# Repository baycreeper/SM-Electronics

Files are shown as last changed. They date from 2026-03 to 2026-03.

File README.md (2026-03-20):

# Foothill High School Supermileage Club  
## Electronics System – Shell Eco-Marathon Vehicle (Prototype)

## ⚡ Overview
This repository contains all electronics-related design, development, and testing for the Foothill High School Supermileage Club’s Shell Eco-Marathon vehicle.

It focuses on the vehicle’s electrical and control systems, including the ECU, wiring, sensors, and data acquisition.

---

## 🎯 Objectives
- Develop a reliable and efficient electronic control system  
- Enable precise fuel and engine management  
- Collect and analyze performance data  
- Ensure safe and robust electrical design

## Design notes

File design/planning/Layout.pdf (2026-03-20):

CSharp

- Vacuum hose
- Power & Distribution
- 12V Accessory battery (LiFePO4 1-2 Ah)

Battery +12V
├─10A fuse─> MainRelay(30) ──> ECU + injector + coil + sensors └─PumpRelay(30) ──> Fuel Pump +
Speeduino Fuel Pump out ──> grounds PumpRelay(85)
Relay(86) ──> +12V switched
Injector - ──> Speeduino INJ1
Ignition Coil - ──> Speeduino IGN1 / IGBT Driver

Total schematic:

+----------------+
| 12V LiFePO4 | |
| | Battery | |
+--------+-------+
| 12 AWG Red (Fused 30A)
v
+----------------+
| Master Cutoff |
| | Switch | |
+--------+-------+
| 12 AWG Red
v
+------------------+
| Fuse / Relay Box |
| | | 6-way sealed | |
+--------+---------+

+------------------------+-------------------------+-------------------+
+--------+--------+ | +--------+--------+ | +--------+--------+
| Main Relay | | | | Fuel Pump Relay | | | Starter Relay | |
| (30A SPDT) | | | | (30A SPDT) | | | | (30A SPDT) | |
+--------+--------+ | +--------+--------+ | +--------+--------+

+-------------+-------------+ | 16 AWG Red | 12 AWG Yellow
| Speeduino ECU + Sensors | |------------------------------> Starter Motor +
| | | | (through ESC if
used)
| | +-------------------+ | |
| | | Fuel Injector(s) |<--+ 18 AWG Yellow, low-side switching
| | +-------------------+
| | +-------------------+
| | | Ignition Coil | |<-- 16–18 AWG Blue, logic coil or IGBT driver
| | +-------------------+
| | +-------------------+
| | | Crankshaft Sensor |<-- 22 AWG Green/White Shielded
| | +-------------------+
| | +-------------------+
| | | TPS | |<-- 22 AWG Orange
| | +-------------------+
| | +-------------------+
| | | MAP | |<-- 22 AWG Gray
| | +-------------------+
| | +-------------------+
| | | IAT | |<-- 22 AWG Violet
| | +-------------------+
| | +-------------------+
| | | CLT | |<-- 22 AWG Brown
| | +-------------------+
| | +-------------------+
| | | O₂ Wideband | |<-- 16 AWG White (Heater + 0–5V signal 22 AWG)
| | +-------------------+

+-------------------+
| Accessory Relay | |------------------> IMU, GPS, HUD, Camera, Horn
| 5–10A Fused | |
+-------------------+
| 18–20 AWG Blue/Green
v

+--------------+
| HC-05 + MCU |--> Tablet RealDash +--------------+

+-------------------+
| E-Stop Switch |
| (cuts master relay)|
+-------------------+
+--> Cuts power to all fused relays / ECU inputs

# Electrical Parts List – Nested by Subsystem

1️⃣Power & Safety

- Battery
- 12V LiFePO4, 1–2Ah
- Connect to master cutoff: 12 AWG Red
- Ground to chassis: 12 AWG Black
- Master Cutoff Switch
- Inline with battery +12V
- Wire: 12 AWG Red
- E-Stop Switch (NC)
- Inline with all critical relay coils
- Wire: 14–16 AWG Red
- Fuse / Relay Block (6-way)

- Holds fuses & relays
- Fuses:

■ ECU / Injectors / Ignition: 10A

■ Fuel Pump: 10A

■ Starter: 30A

■ Accessories: 5–10A

- Wire: same as downstream devices

2️⃣ECU / Speeduino

- Speeduino 0.3.7
- Power +12V: 20 AWG Red (via Main Relay + ECU power fuse)
- Ground: 12 AWG Black
- Arduino Mega 2560
- Mounted to Speeduino PCB
- Inputs / Outputs
- TPS: 22 AWG Orange
- MAP: 22 AWG Gray
- IAT: 22 AWG Violet
- CLT: 22 AWG Brown
- Crank Hall Sensor: 22 AWG Green/White (shielded)
- O₂: 22 AWG White (+16 AWG Red Heater)

- Injectors: 18 AWG Yellow
- Ignition Coil Trigger: 16–18 AWG Blue
- Fuel Pump Trigger: 22 AWG Black (feeds relay)
- Starter Trigger (if using MCU control): 22 AWG Blue/Green

3️⃣Fuel System

- Fuel Pump
- +12V via Fuel Pump Relay output 87
- Fuse: 10A near pump
- Wire: 16 AWG Red
- Ground: Battery GND / chassis, 12 AWG Black
- Fuel Pump Relay
- Coil 85 → E-Stop output
- Coil 86 → Battery +12V
- Injectors
- Low-Side Trigger: Speeduino output, 18 AWG Yellow
- Power: 20 AWG Red from ECU power fuse
- Ground: ECU common GND

4️⃣Ignition System

- Ignition Coil / CDI

- Low-side driver from Speeduino: 16–18 AWG Blue
- +12V power via Main Relay: 16–18 AWG Red
- Fuse: Included in Main Relay branch
- Optional: external small relay if coil >1A
- Crankshaft Position Sensor
- 22 AWG Shielded Green/White
- Signal → Speeduino input

5️⃣Starter System

- Starter Motor
- +12V via Starter Relay output 87
- Fuse: 30A near motor
- Wire: 12–14 AWG Yellow
- Ground: Battery / chassis, 12 AWG Black
- Starter Relay
- Coil 85 → E-Stop output
- Coil 86 → Ignition-on / MCU
- Starter ESC (if brushless)
- Control wires connected to MCU / relay

6️⃣Accessories / Telemetry

- Accessory Relay
- Coil 85 → +12V via Ignition-on (optional E-Stop)
- Coil 86 → Ignition-on / MCU trigger
- Output 87 → Accessories
- Devices
- IMU: 18–20 AWG Red/Black
- HUD Display / Mini OLED: 18–20 AWG Red/Black
- GPS Module: 18–20 AWG Red/Black
- Camera / Horn: 18–20 AWG Red/Black
- Optional HC-05 Bluetooth Module
- Connect to Speeduino serial RX/TX
- 5V logic from Arduino / Speeduino
- Wire: 22 AWG

7️⃣Wiring & Harness Supplies

- Wire
- 12 AWG Red/Black (battery, starter)
- 14–16 AWG Red (relay coil feeds / E-Stop)
- 16 AWG Red (fuel pump, ignition power)
- 16–18 AWG Blue (ignition coil low-side)
- 18 AWG Yellow (injectors)

- 18–20 AWG Red/Blue/Green (accessories)
- 22 AWG Various / Shielded (sensors, triggers)
- Connectors
- Deutsch DT / TE Superseal for critical sensors
- Crimp terminals for relays/fuses
- Male/female pins for ECU / sensors
- Harness Protection
- Braided sleeving
- Heat shrink tubing (3/16–1/4”)
- Cable ties, grommets, rubber pass-throughs \\

PAAAAARTS:

- 12V LiPO4 Battery (w/ BMS and overcurrent protection) **some battery idk ■
- Main fuse box & relay box
■ https://www.amazon.com/Malictele-Pre-Wired-Relays-Sealed-Waterproof/dp/B0CYGQKGHW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 x&pd_rd_i=B0CYGQKGHW&pd_rd_r=0ccad619-9752-4f9c-a397-e825cc a8e9e7&pd_rd_w=BWabo&pd_rd_wg=Dkl5C&pf_rd_p=9ce0d71e-7aca-4 397-8822-32313a4aff8e&pf_rd_r=YBM79NVD1K1HDZCW8GMF&qid=17 59884967&sbo=RZvfv%2F%2FHxDF%2BO5021pAnSA%3D%3D&sprefi x=automotive%2Bfuse%2Bbo%2Caps%2C204&sr=1-3-6024b2a3-78e4-4 fed-8fed-e1613be3bcce-spons&sp_csd=d2lkZ2V0TmFtZT1zcF9zZWFyY 2hfdGhlbWF0aWM&th=1 (https://www.amazon.com/Malictele-Pre-Wired-Relays-Sealed-Waterproof/dp/B0CYGQKGHW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)
- Main, fuel, ignition, starter relays, +1 (to ECU) **GET FOUR ■ https://www.amazon.com/Bosch-0986332030-Relay/dp/B00BHIM4N0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 (https://www.amazon.com/Bosch-0986332030-Relay/dp/B00BHIM4N0?s=industrial)

_6pjIJOkdotmROLds-fhNYCFSRpgm6-MZwHdaVL2wg179iRALKoRrWO 2HftzRYREI59EydOU4_71FkI-wiJcofJA8ib_xxloiDfJ862q5McWQ7dyYA8 OTeCyC95pZgDFxWLzUAT6Cxd6cwxIiP1LeDjGHjQC4sMbdApo3A3hW MGDXL62uquE3oo7url6X_NlMNqz4Ot3UU6Mht_XKwhtkmX5wQl2eM-pn 5Ehns1ViQCJ85cdCNgMeulPYJamHvQMwclC2waPOJwXQjjOcV_L5oCn CSw.2R0y7E6n32U7Tc2AK_UGtvRN4aG31h4pdcQzQ6KqyMM&dib_tag =se&keywords=4+pin+bosch+relays+40A&qid=1759884191&s=industrial &sprefix=4+pin+bosch+relays+40a%2Cindustrial%2C145&sr=1-3 (https://www.amazon.com/Bosch-0986332030-Relay/dp/B00BHIM4N0?s=industrial)
- E-Stop (connect to signal line for main relay) ■ https://www.amazon.com/API-ELE-Warranty-Emergency-Latching-Stianless/dp/B08QD31NNC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 2IjoiMSJ9.o0JLMga4CanfnAaJZnGvPmo8cMM38jChPtEgBaRhodWKAtf YG2sZ6NugYS5MTmdwmcF9rJUZ1Ok1gAzY-Gpa-ApzU-QPTctDBXxXnb 8nJzA42jE24lzyD5k_zYC1TzuRRT1DRGbI5iLHiVpuzJpXf6g0-VxnOMiU_ WRCoFMp9tI14V_8IU04TLUWQf4T89V1UVirAMYJH7nSDJnaIy-UNLZA gkiZs-lH3T5TADT--js.zilyJC3X59NI8hIOy3OikqIApiORAC9azPxZBqZS7T 8&dib_tag=se&keywords=emergency%2Bstop%2Bpush%2Bbutton%2Ba utomotive&qid=1759883196&sprefix=emergency%2Bstop%2Bpush%2Bb utton%2Bautomotiv%2Caps%2C170&sr=8-2-spons&sp_csd=d2lkZ2V0T mFtZT1zcF9hdGY&th=1 (https://www.amazon.com/API-ELE-Warranty-Emergency-Latching-Stianless/dp/B08QD31NNC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)
- 12V-5V convertor (for tablet) [3A fuse]
- https://www.amazon.com/Converter-Module-Output-Adapter-Regulator/dp/B08RBWX2GL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 VH9xdmECVZ0jwP1hnqZ0YLrX33tLWmshWiAj430sqsfUZKdYqSj6XqW9KttgEp GZwl6OSc5wZxtVDTW9besYZTQNYZdCzhF9ErowIhZ3AWHXjZEtzb_YlqXz7Ry WOU9eP0Gu0dDmVYnZAv1Nxin7eTJ4svPEkIBhOPA6sCHp27s1cAyt1O5yGkg bet5HCXCUdVHO5QvAGllQAu-sIR6gv9uUkIhV5PR3a74.WjvNA9GEC6PXa5oV NugpibUZOIEtFGED7wYVzY9-9YY&dib_tag=se&keywords=5v%2B3a%2Busb% 2Bbuck%2Bconverter&qid=1759883591&sprefix=5v%2B3a%2Busbc%2Bbuck% 2Bconverter%2Caps%2C545&sr=8-2-spons&sp_csd=d2lkZ2V0TmFtZT1zcF9hd GY&th=1 (https://www.amazon.com/Converter-Module-Output-Adapter-Regulator/dp/B08RBWX2GL?sp_csd=d2lkZ2V0TmFtZT1zcF9hdGY)
- Fuse assortment (5A-30A) ■ https://www.amazon.com/Liamner-Assortment-Automotive-Motorcycle-Accessories/dp/B0DSJQTBVY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 peOn2UvqdKm4-KeyhsO93sE1x2NUi4XvdQBKWENYU8HDVRTM-iM7D ZoVAi4YQ7BH2KlIXGBoLJdYRIQCJuNfv0LA2f6L-7b5UPXH8tgi-0Kw6FC xEqmEKSL5qeD7cG4XH-ok7DU_j4lqB_mGgoPiuIualk6MRItoIkkT01HMiI Hq171FdEhqpAI7pq0c.TqBq9xa4UnOCYl8BaOFEHiLZZw6a00PaM4aPH 3KboTQ&dib_tag=se&keywords=AOC+mini+fuse+assortment&qid=17598 87110&sprefix=aoc+mini+fuse+assortment%2Caps%2C167&sr=8-1 (https://www.amazon.com/Liamner-Assortment-Automotive-Motorcycle-Accessories/dp/B0DSJQTBVY)
- Fuse for starter motor?
■
- MAXI fuse and holder (60A for battery)

■ https://www.amazon.com/Fastronix-High-Current-Covered-Holder/dp/B071CWH241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 OyDbObYc7h0ohrCkImUPGt8pdZfLrDFRDCbYXeHqOmv13DuO7B0tmn OaXvVvYOAWoR03BNsoLqlYHP-z82-hqLmBUi4kxpRsbyHbDuOqf0W0F 5ahnzg1IufPe0_q6yWC92_R5snAh6xwt-0-jTUQ1G9GMbdngbx_E_WDg K8L-O-7AukdFz7v8afGK4i7gaWwAkEc-KzsRWf4FpOts1__GrNov5VMJy 4FBCi9ZuXv3m2TBPcqU-yCG2Tfqz_Eq5xy5Bccz53BqsCMLU0dZV2P-o HS7qQ_w4CZSv_wCPfvw.s3P_oNkJUBQzijacT2YlqlStRH0rLb-tMhsJGJ 6tWZM&dib_tag=se&keywords=4+gauge+maxi+fuse+holder&qid=175988 5819&s=industrial&sprefix=4+guage+maxi+fuse+hold%2Cindustrial%2C1 49&sr=1-1-spons&sp_csd=d2lkZ2V0TmFtZT1zcF9hdGY&psc=1 (https://www.amazon.com/Fastronix-High-Current-Covered-Holder/dp/B071CWH241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)
- Ground bus bar (gnd for all the big boy current drinkers ex: battery, main relay, starter, fuel pump, ignition coil, etc)
■ https://www.amazon.com/Blue-Sea-Systems-Common-10-Gang/dp/B000K2MA9C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 Gd9FWTFyROoUiB2JJM3rmfct5Z9jAt8608B1yf4tKwMNtOx1bf9goUAQS VTXeVB-E71EPEZy8t9An5igc07s8GqcQmO0IYiqjo50.sg8zklWyqZG9AC XOWXQYlM4hfMfPpOX3ROyA3xjvVBg&dib_tag=se&hvadid=241912403 694&hvdev=c&hvexpln=0&hvlocphy=9032030&hvnetw=g&hvocijid=9473 815932346308800--&hvqmt=e&hvrand=9473815932346308800&hvtargid =kwd-6778157821&hydadcr=24662_10400876&keywords=blue+sea+230 1&mcid=44dfa469103b3366b2c2f3116110850d&qid=1759886674&sr=8-1 (https://www.amazon.com/Blue-Sea-Systems-Common-10-Gang/dp/B000K2MA9C?hvadid=241912403694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)
- Terminal Block
- (to split ECU power to all sensors and HC-05 and ignition relays)
■ https://www.amazon.com/Joinfworld-Terminal-Position-Pre-Insulated-Jumper/dp/B0BN55WVDB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 9032030&hvnetw=g&hvocijid=12081548633357188257--&hvqmt=e&hvra nd=12081548633357188257&hvtargid=kwd-1194057008&hydadcr=2463 0_10399594&keywords=insulated%2Bterminal%2Bblock&mcid=66f90a89 f488390f8d4f5ba1b62b9963&pd_rd_i=B0BN55WVDB&pd_rd_r=6662406 2-985e-4507-91fc-76a4ed1845a3&pd_rd_w=9mHBV&pd_rd_wg=xR0ng& pf_rd_p=9ce0d71e-7aca-4397-8822-32313a4aff8e&pf_rd_r=CMT6YTPY SGJ2YR5PZ857&qid=1759886961&sbo=9ZOMT9Jm0JH%2Ft%2BWi68i DSA%3D%3D&sr=1-2-6024b2a3-78e4-4fed-8fed-e1613be3bcce-spons& sp_csd=d2lkZ2V0TmFtZT1zcF9zZWFyY2hfdGhlbWF0aWM&th=1 (https://www.amazon.com/Joinfworld-Terminal-Position-Pre-Insulated-Jumper/dp/B0BN55WVDB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)
- Common gnd bus (for small sensors)
■ https://www.amazon.com/Bonsicoky-Terminal-Positions-Electrical-Grounding/dp/B097R5J66D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 (https://www.amazon.com/Bonsicoky-Terminal-Positions-Electrical-Grounding/dp/B097R5J66D)

J9.o3aAIQFhu_-oQy_cjH_gGr-I2ZsUD2van3ZxTJFIcuCGtwjsV_0a02c06 xmGgAsweLC_Z7s8BrkThGN9AE2FHt6aSQ5IIX0xm6AywIxyYmkjc037W nkoc7aHFneKdHEK9K7xrVlhkaOnULBed569N-pp-0vxnDiirp3qnsHDPBm eOkuzUH1762MrlZQMN0zGQIZrdOFa-srUtJsQnGndByVy5Y_iN0x7BqRJ wkpjwacSbjMiRnEtuu5OaBVW9xk3zcHL_uoTfN8-jhZxIzkypbC-lzw2f7pjC WYmur6nO-Q.0BQxbNhj80H8sG3uCdPtALvmOI-11KQYgsoqWwOeHoE &dib_tag=se&keywords=ground+bus+bar&qid=1759886729&sprefix=grou nd+bus+ba%2Caps%2C175&sr=8-7 (https://www.amazon.com/Bonsicoky-Terminal-Positions-Electrical-Grounding/dp/B097R5J66D)
- Weatherproof connectors (2,3,4 pin) **NOT for starter, battery, ignition coil, fuel pump
- https://www.amazon.com/Amliber-Ratcheting-Connectors-Automotive-Electrical/dp/B0BZBZHVQ6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 zAnfMxUcfN6BGmdwt5Fa-O5jgd5LWTOkXMDiTed4VdjJUsZi6d2bUyfEGK8lH8jY 5wxCZjeV2T30tmA5C5OToGBfZSgM.FDl0ZpkyE-u2IbWTmRl7XDYJEIyOgQPV hL9bX9JeItI&dib_tag=se&hvadid=703719639063&hvdev=c&hvexpln=0&hvlocph y=9032030&hvnetw=g&hvocijid=16756300949084176163--&hvqmt=e&hvrand=1 6756300949084176163&hvtargid=kwd-377730786898&hydadcr=11111_1366393 0&keywords=deutsch+style+connectors&mcid=107fbdab59613c62889eed84540 b970b&qid=1759887500&sr=8-1-spons&sp_csd=d2lkZ2V0TmFtZT1zcF9hdGY& psc=1 (https://www.amazon.com/Amliber-Ratcheting-Connectors-Automotive-Electrical/dp/B0BZBZHVQ6?hvadid=703719639063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)
- Ring Terminals
- 8 AWG for battery
- Butt splice connectors (heat shrink typed)
- In case a wire is too short or we have some cuts (use solder+silicone for high current loads the big 4)
■ https://www.amazon.com/TICONN-120PCS-Heat-Shrink-Connectors/dp/B0CT3YCD5B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 J9.h2nMOlQHGbm4s-HtC2fI2Mn6QzWhqcSuMnBS7vmVtfj7reFlekePrjO nEPE0T99HzLrJJNGTbhKJvOm_-Ez1LZ69GXCr6ofYBboRl_fx7Wp9PXs TXcyhKwLx7i14xK2z1-PewJSGXrPHWb5LsKe_kELwcM-1Z9T7aCsYow mQQaaOwdLT8mZtj0QZKZi5zMUg6ar-F0_TrM_N-qUhVorWlDfxydkMC7 BDQEWOQjdQR1s.eirYoBGIm_v91z-uYityp1qdKbkgUVmnK7849dazY90 &dib_tag=se&keywords=butt%2Bsplice%2Bconnectors&qid=1759888070 &sprefix=butt%2Bsplice%2Bcpnnector%2Caps%2C181&sr=8-2-spons&s p_csd=d2lkZ2V0TmFtZT1zcF9hdGY&th=1 (https://www.amazon.com/TICONN-120PCS-Heat-Shrink-Connectors/dp/B0CT3YCD5B?sp_csd=d2lkZ2V0TmFtZT1zcF9hdGY)
- Wires
- 16 AWG
- 14 AWG
- 12 AWG
- 8 AWG
- Wire loom
- https://www.amazon.com/Keco-100ft-Expandable-Braided-Sleeving/dp/B07K1XJNJN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 (https://www.amazon.com/Keco-100ft-Expandable-Braided-Sleeving/dp/B07K1XJNJN?sp_csd=d2lkZ2V0TmFtZT1zcF9tdGY)

_GcjXVTBsnnylxO8rXuyvDd9CJXLN1dBDwPHXRQ134gVffN5JSnXL5Ig-Bp0lovI CQUDsoAUzaELJ8_rCftOajxk95Zv5_x7ri-YDqtbYowp2Khj6_by7HNDUTme49W MpIX9sorwrS_ahVBW5CEr9_1eAIaKI4gRMUkxxGbPDXJWQOjO2dwwBTr3qJ6 T_kZd8ytMnHG1c_snYg0bb9tHprbSWjys5pHL0w.XJ5h0lHsc4v_z16W0fzsh5b5T xc_lgPtqekMdtYSJlw&dib_tag=se&keywords=techflex%2Bloom%2Bautomotive& qid=1759888848&sprefix=techflex%2Bloom%2Bautomotiv%2Caps%2C149&sr= 8-12-spons&sp_csd=d2lkZ2V0TmFtZT1zcF9tdGY&th=1 (https://www.amazon.com/Keco-100ft-Expandable-Braided-Sleeving/dp/B07K1XJNJN?sp_csd=d2lkZ2V0TmFtZT1zcF9tdGY)
- Heat shrink tubing assortment
- https://www.amazon.com/108PCS-Heat-Shrink-Tubing-Kit/dp/B0FB8PD9NF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 sl77dMhn6QpNs5sBhJv7Ajw.aEplN0LRMrwJIMhf3a2GQ84KmMHfjLaUV3J_0uP xlbo&dib_tag=se&keywords=color%2Bheat%2Bshrink%2Bassortment&qid=1759 889009&sprefix=color%2Bheat%2Bshrink%2Bassortment%2Caps%2C150&sr=8 -4&th=1 (https://www.amazon.com/108PCS-Heat-Shrink-Tubing-Kit/dp/B0FB8PD9NF)
- Neutral cure silicone
■ https://www.amazon.com/BTAS-Dielectric-Automotive-Electrical-Connectors/dp/B0D6R543V2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 KeyAOrtvaDxkNA3cSqk-0hemI5krS4vBrAfuoY3ruGEsbQImrwVigZN42u QZ5lVL3gBm0r9X2TKh1yfS6WzDFam9fzm-dMgCUTU-LJMCiOkPOpwpu UNLwqGut8PCif7Y.4751hMK7ELW831SXGCY_57PYj5BGMBwtKBNxn2 heMv0&dib_tag=se&keywords=electronic%2Bsilicone&qid=1759889237& sprefix=electronic%2Bsilico%2Caps%2C166&sr=8-1-spons&sp_csd=d2lk Z2V0TmFtZT1zcF9hdGY&th=1 (https://www.amazon.com/BTAS-Dielectric-Automotive-Electrical-Connectors/dp/B0D6R543V2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)
- Fireproofing silicone
- https://www.amazon.com/Visbella-Temperature-Waterproof-Combustion-Automotive/dp/B0CPNZNQC4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 9.CC41cRqb5Un1Oyc3A4BxudsGjV14kJ2j0IIZ-QyAqBwTkDnj510G-Nu94b9VYA L-65Hhs8DwRu1LSFKiIYXEKkzZLr-LPeA88z79s-8731N2UK7gdo7UHihJF1SJwI GNAPaBwyDUgEu7fMkuEybEvHuDLRZyItReXrXu88vhOSuHyXE0eMQnZ-ch6P vgym0iLmTVsmTV0ebciaqPMKEibhP4O3fJAkj8_3YRsWwOADM.9eP6iTOxUfpK h7DYh-XDV2bOLUVV2U6EuO4jYPNgxV4&dib_tag=se&keywords=RTV%2Bhigh %2Btemp%2Bsilicone&qid=1759889310&sprefix=rtv%2Bhigh%2Btemp%2Bsilico n%2Caps%2C166&sr=8-2-spons&sp_csd=d2lkZ2V0TmFtZT1zcF9hdGY&th=1 (https://www.amazon.com/Visbella-Temperature-Waterproof-Combustion-Automotive/dp/B0CPNZNQC4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)
- Wire grommets (to pass through chassis)
- https://www.amazon.com/Double-Sided-Rubber-Grommets-Assorted-Waterproof/dp/B0B5VYYSCM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 wxxGOWEZAQZkc6mruKeFpLs6y1Kr1aOI1QXf74qrZemUR11gmWpaVdolI-G7L (https://www.amazon.com/Double-Sided-Rubber-Grommets-Assorted-Waterproof/dp/B0B5VYYSCM)

B7rGyG5PXoaCJYmlTM4Voc6WOhWRF_mXBU_amE-V-uKh_PCWxk.-TKhooN mu9NkNOOkLtq5xzSXLe3WUY8PGt4W3qK5SIw&dib_tag=se&keywords=wire% 2Bgrommets&qid=1759889343&sprefix=wire%2Bgrommet%2Caps%2C174&sr= 8-4&th=1 (https://www.amazon.com/Double-Sided-Rubber-Grommets-Assorted-Waterproof/dp/B0B5VYYSCM)
- Main battery cutoff switch
- https://www.amazon.com/Current-Battery-Disconnect-Isolator-Vehicle/dp/B0B7DR5H4H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 RwK336itQgbzR0keuOdReoqE8D_Dinu-Kz_87ZF013Y.k-_qxZe28S5i-bZT0qkU CEavM1MGbCwksUQz3gxEJ2Y&dib_tag=se&keywords=300A%2Bbattery%2Bdi sconnect%2Bswitch&qid=1759890339&sprefix=300a%2Bbattery%2Bdisconnect %2Bswitch%2Caps%2C183&sr=8-2-spons&sp_csd=d2lkZ2V0TmFtZT1zcF9hdG Y&th=1 (https://www.amazon.com/Current-Battery-Disconnect-Isolator-Vehicle/dp/B0B7DR5H4H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)

Extra:
Crimping tool
Multimeter
ECU enclosure box (are we making this?)

Final Wire List + **8 AWG wire for battery and starter

AWG | Color | Total Approx
Length

Use

12 AWG Red | 8 ft | Battery + main fuse + main relay + starter
12 AWG Black 4–5 ft | Battery negative → main ground bus / high-current
grounds
14 AWG Red | 6 ft | Main relay → fuel pump + ignition coil
14 AWG Black 3 ft | Medium-current grounds (fuel pump, ignition coil if not
chassis grounded)
16 AWG Red | 6–7 ft | ECU 12 V power input + small accessories + 5 V
step-down for tablet
16 AWG Black 12 ft | ECU / sensor grounds (split to sensors and relay coils)
16 AWG Blue | 15–20 ft | All low-current signals: TPS, MAP, IAT, CLT, Hall
sensors, HC-05, relay coils

⚙️ Core Power & Distribution

Item | Notes / Verdict
✅ 12V LiFePO₄ Battery | Perfect. 1.5–3 Ah minimum for EFI. Get one with BMS and overcurrent protection. Example: Antigravity or Shorai.
✅ Main Fuse Box | Essential. 6–8 way ATC/ATO fuse block with positive bus (Blue Sea Systems or Littelfuse).

✅ Main Relay (ECU) Good. 30–40 A automotive relay, standard SPST (Bosch-style).
| Triggers from ignition switch or E-stop return.

✅ Fuel Pump Relay Yes — same type as main relay (use socket base with pigtail).

✅ Ignition Coil Relay | Optional — if Speeduino coil output drives an igniter directly, relay not needed; but keep it for safe power control.
✅ Starter Relay | Mandatory — use a heavy-duty solenoid relay (40–100 A) depending on your starter motor draw.
✅ E-Stop | Great — choose normally closed (NC) style; wire inline with main relay trigger.
✅ 12 V → 5 V Converter (Tablet) | Good. Choose buck converter (5 A rated), 15–20 W output. Example: DROK 12V→5V 5A USB module.
✅ Fuse assortment (5A–30A) | Yes — standard ATO or mini-blade fuses.
✅ Ground Bus Bar | Yes. Use for all return grounds to battery/chassis. Get one with 6–10 screw terminals.
⚠️ Terminal Block | Keep one only. Use to split +12 V switched power for sensors, HC-05, and ignition enable. Make sure it’s rated for 15 A+ and insulated.

🔌 Connections

Item | Notes / Verdict

✅ Weatherproof Connectors (2,3,4 pin)

Excellent. Get Deutsch DT or Superseal 1.5 kits.

2-pin → IAT/CLT | Perfect.
3-pin → TPS, MAP, HC-05 | Yes.
4-pin → Injector/Coil | Yes — or 2-pin if each gets its own plug.
✅ Ring Terminals (12 AWG) | Keep — for battery, ground bar, and heavy gauge wires only.
✅ Butt Splice Connectors (heat-shrink type) | Absolutely. Get marine-grade.
✅ Inline Fuse Holder (for ECU Power) | Yes — 5A fuse inline before ECU’s +12V input.

🧵 Wiring

Gauge | Purpose | Notes
12 AWG | Battery → Main Relay, Starter Relay | Silicone-insulated, high current.
14 AWG | Relay → Fuse Box feeds, Fuel Pump | Handles 10–15 A safely.
16 AWG | Ignition Coil, Injector Power | Perfect balance of flexibility & capacity.
18 AWG | Sensors, ECU signal lines | Standard automotive control wire.
✅ Wire Loom | Yes — PET braided or split corrugated for protection.
✅ Cable Labels | Highly recommended — saves debugging headaches. Get adhesive heat-shrink ones or write-on tags.

🔧 Tools / Accessories

Item | Notes / Verdict

✅ Crimping Tool Must be a ratcheting crimper compatible with Deutsch/insulated terminals. IWISS and Wirefy make good ones.

✅ Multimeter For continuity checks, ground verification, voltage testing.

✅ ECU
Enclosure Box

Absolutely — either a 3D-printed or aluminum case. If mounting near engine, use a sealed box with grommets.

⚠️ Add These (You’ll Need Them)

Item | Purpose
Heat-shrink tubing assortment | For sealing soldered joints and strain relief.

Neutral-cure silicone (sensor
safe)

For sealing joints and connectors.

Wire grommets / strain reliefs Where the harness passes through panels or boxes.

Relay sockets with pigtails | Cleaner install for 4-5 pin Bosch relays.
Grounding ring / chassis lug | To tie the ground bus to frame solidly.
Main battery cutoff switch | For absolute power isolation when servicing.

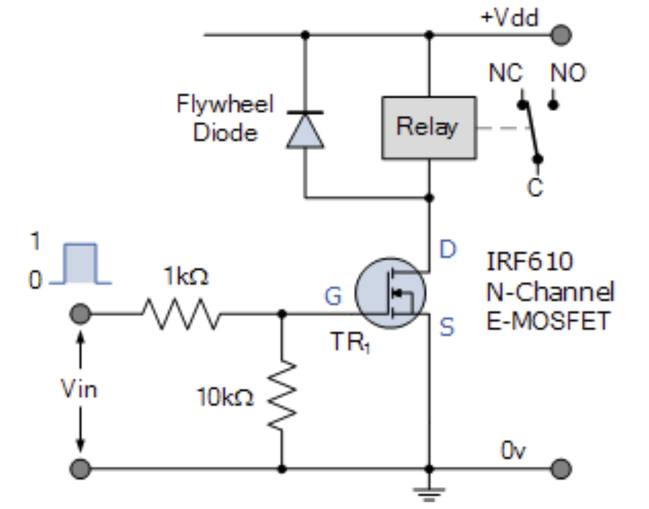
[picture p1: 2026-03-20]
design/planning/flyback diode circuit.png

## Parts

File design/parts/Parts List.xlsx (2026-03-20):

 | Description | Link | Price | Quantity | Subtotal | Total |  | DO NOT EDIT COLUMNS
 | diode-protected relay socket | https://www.amazon.com/ARTGEAR-Harness-Color-Labeled-Automotive-Motorcycle/dp/B078T8CMF6 | $7.99 | 2 | $15.98 | w/out tax | $737.65 | 737.65
 | automotive bosch relay | https://www.amazon.com/Bosch-0986332030-Relay/dp/B00BHIM4N0 | $11.29 | 3 | $33.87 | w/ tax | $813.26
 | 12 socket fuse box | https://www.amazon.com/DaierTek-Indicator-Waterproof-Terminals-Automotive/dp/B0CGT91KTR?hvadid=636053227156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 | $15.99 | 1 | $15.99 |  | AP FIND ANOTHER 6A 12V charger specifically designed for LiPO!!!!
 | ATC/ATO fuse assortment | https://www.amazon.com/ZIPCCI-Standard-Fuse-Assortment-Accessories/dp/B0B18NVT5Z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 | $8.99 | 1 | $8.99
FALSE | 275A (positive) kill switch | https://www.amazon.com/GOGONFLY-Battery-Disconnect-Isolator-Vehicles/dp/B0981PHXLK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 | $12.49 | 1 | $12.49
 | 2 250A bus bars (4BIG and 6SMALL screws per) | https://www.amazon.com/Mofeez-Power-Distribution-Screws-Terminals/dp/B0DGLC9XFT?sp_csd=d2lkZ2V0TmFtZT1zcF9hdGY | $29.99 | 1 | $29.99
FALSE | wire end caps (for loose relay socket wires) | https://www.amazon.com/Tmyjfjingxi-620PCS-Connectors-12-10AWG-Electrical/dp/B0DR8FRBT2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 | $8.99 | 1 | $8.99
FALSE | heat shrink (900pk was cheaper than 200pk) | https://www.amazon.com/Eventronic-Heat-Shrink-Tubing-Kit-3/dp/B0C8STNGB8 | $9.99 | 1 | $9.99
 | terminal blocks/bus bars (using 3) | https://www.amazon.com/Terminal-Position-Block-Insulated-Electrical/dp/B0BTYHGJK1 | $9.24 | 1 | $9.24
 | ring terminals for bus bars | https://www.amazon.com/haisstronica-Non-Insulated-Connectors-Terminals-Electrical/dp/B09YCRNGP9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 | $26.99 | 1 | $26.99
 | MAXI fuse assortment | https://www.amazon.com/30pcs-Maxi-Fuses-Assortment-Kit/dp/B0BGZMYJ19?sp_csd=d2lkZ2V0TmFtZT1zcF9hdGY | $16.88 | 1 | $16.88
 | MAXI fuse holder | https://www.amazon.com/SCOSCHE-PMFHIKF-Maxi-Fuse-Holder/dp/B072JHSW5J | $12.81 | 2 | $25.62
 | inline fuse holder 2pk 12AWG 30A | https://www.amazon.com/Inline-Fuse-Holder-Waterproof-XIOGZAXI/dp/B0C9V2SW8K?hvadid=409954635979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 | $5.39 | 1 | $5.39
 | butt connectors for joining cut wires (don't solder) | https://www.amazon.com/Connectors-Waterproof-Electrical-Kit-Thickened-Automotive/dp/B0FS123Z2V | $4.99 | 1 | $4.99
 | deutch connector kit (for the sensors, etc.) | https://www.amazon.com/Twippo-Automotive-Electrical-Waterproof-Connectors/dp/B0DQ5DK3TM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 | $26.99 | 1 | $26.99
FALSE | 10A Emergency Stop NO/NC | https://www.amazon.com/Emergency-Latching-Aluminum-Waterproof-Self-Locking/dp/B0BZTPQ1CJ | $11.99 | 2 | $23.98
 | logic level relays 4 channel 2pk | https://www.amazon.com/ANMBEST-Channel-Optocoupler-Expansion-Raspberry/dp/B08PP8HXVD | $9.99 | 1 | $9.99
 | rocker switch with safety cover (spark kill, ign) | https://www.amazon.com/Gebildet-12V-24V-Universal-Rocker-Waterproof/dp/B07KQ2R6G4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 | $7.99 | 1 | $7.99
 | LED momentary pushbutton | https://www.amazon.com/Gebildet-Stainless-Momentary-12V-24V-Waterproof/dp/B07YDHPDD7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 | $6.99 | 1 | $6.99
 | (speeduino sensor GND) bus bar | https://www.amazon.com/RVBOATPAT-Distribution-Terminal-Battery-Automotive/dp/B0F6SC5C3Q?s=industrial | $9.99 | 1 | $9.99
 | ferrule connector kit (w/ crimpers) 7-22AWG | https://www.amazon.com/KAIWEETS-Crimping-Self-adjustable-Terminals-Connectors/dp/B0BQ6LQ12G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 | $24.99 | 1 | $24.99
FALSE | PET wire loom (1/2 and 1/4in 25 ft each) | https://www.amazon.com/Keco-100ft-Expandable-Braided-Sleeving/dp/B08CKRLS2M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 | $10.99 | 1 | $10.99
 | PCB to wire connectors (BT, start, 5V, GND, relay) | https://www.amazon.com/Connector-pre-crimped-Housing-Adapter-Compatible/dp/B08G188ZQ8 | $16.99 | 1 | $16.99
 | 12 AWG 12 ft | https://www.wiringdepot.com/store/p/669-Automotive-Primary-Wire-12-AWG-12-Ft-Cut.aspx | $5.46 | 1 | $5.46
 | 12 AWG 12 ft | https://www.wiringdepot.com/store/p/669-Automotive-Primary-Wire-12-AWG-12-Ft-Cut.aspx | $5.46 | 1 | $5.46
 | 16 AWG 20 ft | https://www.wiringdepot.com/store/p/677-Automotive-Primary-Wire-16-AWG-20-Ft-Cut.aspx | $5.46 | 1 | $5.46
 | 16 AWG 20 ft | https://www.wiringdepot.com/store/p/677-Automotive-Primary-Wire-16-AWG-20-Ft-Cut.aspx | $5.46 | 1 | $5.46
 | 22 AWG 23 ft (BLACK, RED, YELLOW) | https://www.amazon.com/DAOKAI-Silicone-Stranded-Electrical-Printer/dp/B09TK155BW?s=industrial | $9.99 | 2 | $19.98
 | 4 AWG 25 ft each (BLACK, RED) | https://www.amazon.com/Gauge-Copper-Aluminum-Terminal-Connectors/dp/B0CJQZ4FBQ?hvadid=174247234454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 | $40.99 | 1 | $40.99
 | BATTERY 12V LiPO4 w/ BMS 90A peak 30A cont. | https://newportvessels.com/products/newport-12v-30ah-lithium-battery?variant=51646900207983 | $144.99 | 1 | $144.99
FALSE | Victron 12V 5A charger | https://expion360.com/products/blue-smart-ip65-charger-6v-12v-1-1-120v-nema-1-16?variant=46345786556579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 | $85.00 |  | $0.00
 | terminal clamp M10 | https://www.amazon.com/Uenede-Connectors-Terminals-Application-Motorcycles/dp/B0D3D4MXXS | $8.49 | 1 | $8.49
 | M6 battery post | https://www.amazon.com/XS-Power-586-Adaptor-Thread/dp/B004XH69MY | $14.99 | 1 | $14.99
FALSE | terminal post boot | https://www.amazon.com/Ohleats-Battery-Terminal-Cover-Accessories/dp/B0D2Q3PM2K | $4.69 | 1 | $4.69
FALSE | snail horn | https://www.amazon.com/Waterproof-Electric-Motorcycle-scooter-mopeds/dp/B08R5RWFS4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 | $10.88 | 1 | $10.88
FALSE | momentary push button (for horn) | https://www.amazon.com/Daiertek-Momentary-Switch-Waterproof-Toggle/dp/B07RX68J5B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 | $8.99 | 1 | $8.99
FALSE | wago connectors | https://www.amazon.com/Compact-Splicing-Connector-Assortment-221-2401/dp/B0CJ5QF4Z2 | $9.95 | 1 | $9.95
FALSE | speedometer HUD | https://www.amazon.com/GUGUMO-Speedometer-Universal-Automatic-Vibration/dp/B0CSYYWXFS | $12.59 | 1 | $12.59
FALSE | DC 12V to 2x USB (for charger and speedometer) | https://www.amazon.com/YIPIN-HEXHA-Converter-Female-Adapter/dp/B0B24MF21J?hvadid=616861174053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 | $8.99 | 1 | $8.99
FALSE | Hydraulic Crimper AWG 12-2/0 | https://www.amazon.com/dp/B0F8HFWPX5?titleSource=true | $49.99 | 1 | $49.99
FALSE | Ratchet Crimper AWG 22-6 | https://www.amazon.com/dp/B0FLCTSN8K?titleSource=true | $15.99 | 1 | $15.99

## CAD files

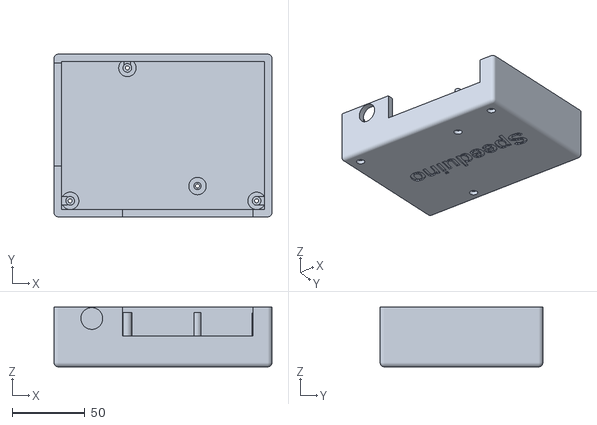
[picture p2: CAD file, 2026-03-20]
design/CAD/speeduino/Speeduino_v03_top (1).stl
150.0 x 112.0 x 41.1

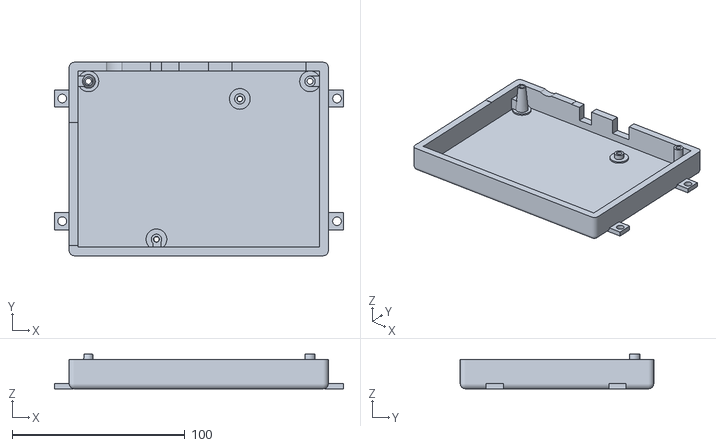
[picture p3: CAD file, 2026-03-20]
design/CAD/speeduino/Speeduino_v03_base (1).stl
167.2 x 112.0 x 20.0

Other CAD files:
design/CAD/enclosure/Electronics+Enclosure+Drawing.dwg
design/CAD/aluminum extrusions/3030+100mm.f3d
design/CAD/aluminum extrusions/3030+150mm.f3d
design/CAD/aluminum extrusions/3030+200mm.f3d
design/CAD/aluminum extrusions/3030+300mm.f3d
design/CAD/enclosure/3030+Joining+Plate.f3d
design/CAD/enclosure/Electronics+Enclosure.f3z
design/CAD/enclosure/adapter.f3d
design/CAD/enclosure/battery.f3d
design/CAD/enclosure/bus+bar+mock.f3d
design/CAD/enclosure/control+panel.f3d
design/CAD/enclosure/frame.f3d
design/CAD/enclosure/fuse+box+mock.f3d
design/CAD/enclosure/speeduino+mock.f3d
design/CAD/relaybox/relaybox2 (1).f3d
design/CAD/relaybox/relayboxbottom.f3d
design/CAD/relaybox/relayboxtop (1).f3d
